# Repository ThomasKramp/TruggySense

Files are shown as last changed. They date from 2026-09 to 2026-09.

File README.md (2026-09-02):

# TruggySense

This repository contains two generations of the project:

| Folder | Description |
|---|---|
| [`TruggySense_v1`](./TruggySense_v1) | Original system, developed by **[Robbe Elsermans](https://github.com/RobbeElsermans)**. Companion paper: [arXiv:2505.07399](https://arxiv.org/abs/2505.07399) |
| [`TruggySense_v2`](./TruggySense_v2) | Hardware and firmware redesign for reproducibility, developed by **Thomas Kramp**, building on v1 |

Each subfolder has its own README with details on `cad/`, `code/`, and `docs/`.

---

## License

Unless stated otherwise, **original content created for this project** — documentation,
CAD/schematic designs, and project-authored source code — is licensed under
**[CC BY-SA 4.0 (Attribution-ShareAlike 4.0 International)](https://creativecommons.org/licenses/by-sa/4.0/)**.
The full legal text is in [`licence.txt`](./TruggySense_v1/licence.txt) (identical copy also in `TruggySense_v2/`).

In short, if you reuse or build on this work you must:
- **Attribute** the original creator(s) (Robbe Elsermans for v1, Thomas Kramp for v2) and link back to this repository,
- **Indicate any changes** you made,
- **Share any adapted/derivative version under the same license** (CC BY-SA 4.0 or a compatible license).

### What this license does *not* cover

CC BY-SA is intended for creative/documentation works, not for reused third-party software or hardware libraries. The following are **excluded** from the CC BY-SA grant above and remain under their own original licenses/terms:

- **Third-party code libraries** vendored under `code/**/lib/` (e.g. encoder libraries, `TimerInterrupt_Generic`, and similar dependencies pulled in via PlatformIO or copied manually). Check each library's own header/license file or upstream repository before reuse.
- **Vendor-exported component/footprint libraries** under `cad/KiCAD/**` (e.g. `Capture/`, `Quadcept/`, manufacturer `.zip` libraries). These originate from component manufacturers or distributors and are subject to their own terms.
- **Any datasheet, manual, or reference material** included for convenience (e.g. under `docs/`), which remains the property of its original publisher.
- **Trademarks and product names** referenced in this project — including *Team Corally Kagama*, *Teensy*, and other component/brand names — belong to their respective owners. Their use here is purely descriptive (identifying compatible hardware) and does **not** imply affiliation with, sponsorship by, or endorsement from those companies.

If you plan to redistribute or build a product on top of this repository, you are responsible for independently verifying the license terms of any third-party component you rely on.

### Hardware & safety disclaimer

This project involves custom electronics (battery connections, power protection, motor control) built for an RC vehicle platform. It is shared **as-is, for research and educational purposes**:

- No warranty is made regarding the safety, reliability, or fitness of any design for a particular purpose — see the full disclaimer in Section 5 of [`licence.txt`](./TruggySense_v1/licence.txt).
- Building or operating hardware based on this repository (batteries, power electronics, motorized vehicles) carries inherent risk. Do so at your own risk and with appropriate care.
- The authors and Cosys-Lab / University of Antwerp accept no liability for damages, injury, or losses arising from use of this material.

### Note on university/thesis materials

This repository is the output of Master's thesis work supervised by Cosys-Lab. Any university-internal documents (guidelines, templates) are included for context only and remain the property of the University of Antwerp; they are not licensed for reuse under the terms above.

---

## Questions about reuse or licensing

Open an issue on this repository, or reach out via Cosys-Lab, University of Antwerp.

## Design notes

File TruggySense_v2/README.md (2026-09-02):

# TruggySense: Hardware and Firmware Redesign for Reproducibility

The continuation of the [TruggySense](https://github.com/Cosys-Lab/TruggySense), that was  originally developed by Robbe Elsermans, a new off-road era of (autonomous) RC-vehicle.

Further developed by Kramp Thomas through Cosys-Lab at University of Antwerp.

Welcome to the readme! A list of what this repo includes

- all files related to the end product,
- source code,
- manuals of the final system.

## cad
Everything related to specialized mounts, holders, and cases to build upon the Team Corally Kagama 1/8 RC vehicle chassis. 
Furthermore, it contains also schematics and circuits drawn in KiCAD.

## code

## docs

## Future perspectives

## licence
BY-SA 4.0 (Attribution-ShareAlike 4.0 International)
See [licence.txt](licence.txt) for the disclaimer

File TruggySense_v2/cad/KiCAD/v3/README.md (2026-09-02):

## KiCAD

- **1_logic_board**:        The board-design and electrical schematic that contains the LLC, most sensors and connector points.
- **2_power_board**:        The board-design and electrical schematic that contains the connection to the battery and provides power to the motors.
- **sensor_position**:      The board-design and electrical schematic of the GNSS/GPS module.
- **sensor_temperature**:   The board-design and electrical schematic of the temperature sensor.

- **io_protection_buffer**: An electrical schematic of the protection buffer, for certain input purposes, used in the logic board.
- **io_protection_input**:  An electrical schematic for the input protection, used in the logic board.
- **io_protection_output**: An electrical schematic for the output protection, used in the logic board.

- **layout_nrf24l01**:      A generic board-layout for nRF24L01 modules, used in the logic board.
- **layout_pim448**:        A generic board-layout for motion sensor, used in the logic board.

- **recreation_ina219**:    A recreation of both the electrical schematic and board-design, for the low-current sensor.
- **recreation_lm2596**:    A recreation of both the electrical schematic and board-design, for the voltage converter (5V --> 3V3).

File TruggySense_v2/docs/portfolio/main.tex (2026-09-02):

\documentclass[ti,oneside,10pt]{uantwerpenreport}
% Run in terminal:  export TEXINPUTS=.:./classes//

\usepackage[english]{babel} % load the proper language(s)

% ---------------------- Document variables ----------------------
\title{TruggySense: Hardware and Firmware Redesign for Reproducibility}
\subtitle{Master's Thesis Portfolio}
\author{Thomas Kramp}
\affiliation{University of Antwerp | Department Electronics, Information and Communication Technology}
\address{Groenenborgerlaan 171, 2020 Antwerpen, Belgium\\
    M:\@ thomas.kramp@student.uantwerpen.be
}
\extra{Portfolio}
\versionyear{2026}

\titlepageimage{images/design/assembly/v2/full_assembly.png}
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
                \midrule
                    \csvreader[
                        head to column names,
                        late after line=\\,
                    ]{./databases/modules#2/stock.csv}{}{
                        \raggedright\Component &
                        \StockAndPrice{\DigiKeyStock}{\DigiKeyPrice}{\DigiKeyURL} &
                        \StockAndPrice{\FarnellStock}{\FarnellPrice}{\FarnellURL} &
                        \StockAndPrice{\MouserStock}{\MouserPrice}{\MouserURL} &
                        % Optional columns
                        \UseOptionalSupplier{#4} &
                        \UseOptionalSupplier{#5}
                    }
                \bottomrule
            \end{tabular}
        \end{adjustbox}
        \label{tab:#1_available_stock}
    \end{table}
    \vspace{-9pt}
    \noindent\textit{This stock was checked on #3.}
    \par\smallskip
}

% Old-New image comparison
\usepackage{pgffor} % for loops

\newcommand{\DualColumnWidth}{0.47}

\newsavebox{\ImgA}
\newsavebox{\ImgB}
\newlength{\ImgHA}
\newlength{\ImgHB}

\newcommand{\ImageComparison}[3]{
    % #1 = main caption
    % #2 = main label
    % #3 = list: {imgA/capA/imgB/capB, ...}

    \begin{figure}[h!]
        \centering
        \caption{#1}
        \label{fig:#2}

        \foreach {\imgA}/{\capA}/{\imgB}/{\capB} in {#3} {

            % Measure images at fixed width
            \sbox{\ImgA}{}
            \sbox{\ImgB}{}
            \setlength{\ImgHA}{\ht\ImgA}
            \setlength{\ImgHB}{\ht\ImgB}

            \begin{subfigure}{\DualColumnWidth\textwidth}
                \centering
                \ifdim\ImgHA>\ImgHB
                    % Image A is taller → scale it down
                    
                \else
                    % Image A is smaller → keep width
                    
                \fi
                \caption{\capA}
            \end{subfigure}
            \begin{subfigure}{\DualColumnWidth\textwidth}
                \centering
                \ifdim\ImgHB>\ImgHA
                    % Image B is taller → scale it down
                    
                \else
                    % Image B is smaller → keep width
                    
                \fi
                \caption{\capB}
            \end{subfigure}

            \par\vspace{0.5em} % new row spacing
        }
    \end{figure}
}
\newcommand{\ComponentTable}[1]{
    The components used are:
    \Needspace{10\baselineskip}
    \begin{table}[h!]
        \centering
        \begin{adjustbox}{max width=\textwidth}
            \begin{tabular}{L{2.5cm} c c l}
                \toprule
                    \textbf{Component} & \textbf{Tag} & \textbf{Name} & \textbf{Function} \\
                \midrule
                    \csvreader[
                        head to column names,
                        late after line=\\,
                    ]{./databases/design/#1}{}{
                        \Component & \Tag & \Name & \Function
                    }
                \bottomrule
            \end{tabular}
        \end{adjustbox}
    \end{table}
}
\newcommand{\BomLink}[2]{
    \IfStrEq{#2}{-}{#1}{                    % If
        \href{#2}{\textbf{#1}}   % Else
    }
}

% Setup checks
\usepackage{pifont}
\newcommand{\cmark}{\ding{51}} % ✔
\newcommand{\xmark}{\ding{55}} % ✘

% I²C highlight command
\usepackage{soul}
\newcommand{\IICUses}[1]{\textcolor{teal}{#1}}
\newcommand{\IICForb}[1]{\textcolor{purple}{\st{#1}}}

\sisetup{
    detect-all,
    group-separator = {,},
    group-minimum-digits = 4
}
\makeatletter
% \csvset{
%     before reading=\catcode`\%=12
% }
\makeatother

\begin{document}
\maketitle

\frontmatter
\tableofcontents

\mainmatter
% To Do list:
% - Complete AI usage document.

\chapter{Introduction}
% ---------------------- Introduction ----------------------
Last year, as of 2026, the development towards a off-road Remote Controlled Vehicle, called the TruggySense, started.
The system included sensors that could measure speed, acceleration, orientation, power consumption, temperature and location in real-time.
This was needed, since it was the groundwork, towards creating an Advanced Data Acquisition System (ADAS).
Eventually the goal is to add technologies that are present in most of todays smart cars, such as: anti-lock braking system (ABS), lane keeping, and traction control.

The thesis had proven to be able to gather real-time data, resulting in an astounding success, though it had a glaring flaw that led to two problems.
The assembly of the TruggySense Version 1 (TSV1) was complex and fault-prone (as shown in Fig.~\ref{fig:truggysense_version_1}).
This would mean that duplicating or modifying the system, would need rigorous debugging and be notably time-consuming.

\begin{figure}[h!]
    \centering
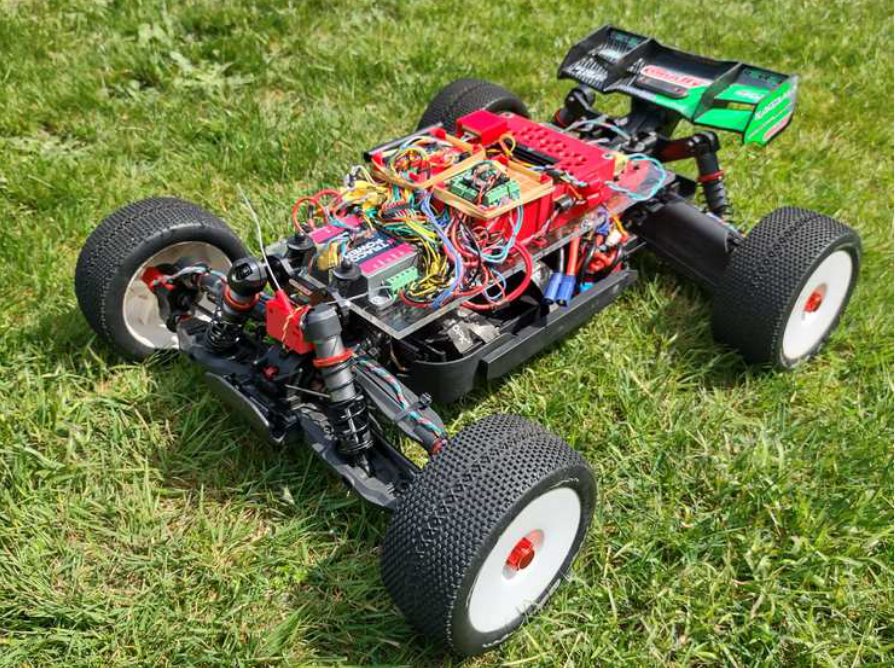
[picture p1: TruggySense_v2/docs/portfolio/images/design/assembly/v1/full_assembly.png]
	
	\caption{
		TruggySense version 1.
	}
	\label{fig:truggysense_version_1}
\end{figure}

To solve this, most of the components shall be integrated on a custom-made Printed Circuit Board (PCB).
Besides this other expansions this project will aim to include are:
\begin{itemize}
    \item Support for Individual Wheel Drive (IDW).
    \item Expansion possibility to add redundancy.
    \item Integration of ROS2 (Robot Operating System 2).
\end{itemize}

\subsection{Available middleware}
Note that a previous attempt was made to integrate ROS2 on the TruggySense.
Alternatives for this include ArduPilot, PX4, ZeroMQ, and LCM (Lightweight Communications and Marshalling).
Each of them having their advantages and disadvantages:
\begin{itemize}
    \item ArduPilot and PX4 are competitors of each other, both boasting an open-source autopilot firmware.
          These projects were specifically designed for aerial vehicles, later adding support for land vehicles.
          With both ArduPilot and PX4 being designed for autonomy, which isn't suitable for Remote Controlled Vehicles (RCV);
          and having a high reliance on GPS data, which isn't always available in off-road situations.
    \item ROS2 as an open-source middleware framework, working with a Pub-Sub system.
          This project is known to have high latency or bandwidth budgeting, creating the need to alter the software for real-time applications.
    \item ZeroMQ and LCM are open-source messaging libraries, with LCM focussing on real-time data acquisition.
          These projects are both ethernet dependent, ZeroMQ working with TCP and LCM working with UDP.
          With ZeroMQ having no built-in reliability, needing to built your own reconnection and packet loss handling;
          and LCM acting more as a logger than a communication step between the controllers.
\end{itemize}

For this thesis we will continue on the assumption that ROS2 will be implemented, despite its latency issues.

\subsection{Conclusion}
Most of the ground work has been done, yet a small part of the documentation provided is either conflicting, false or non-existing.
Thus this will be an iterative project, first creating a prototype and based on the results and inevitable mishaps a full-fletched PCB will be created.
The goal of this project will be to create second iteration of the TruggySense (TSV2), that will provide a similar performance to the TSV1, but is easier to assemble.

\chapter{Modules and Sensors}       % ---------------------- Modules and Sensors ----------------------
\section{Framework layout} 
The TruggySense makes use of two controllers: A High Level Controller (HLC) and Low Level Controller (LLC).

The LLC will act as a Data Acquisition System (DAQ), control the base components of the RCV and communicate with other components.
The modules used for these purposes are:
\begin{table}[h!]
    \centering
    \begin{tabular}{p{0.3\textwidth}p{0.3\textwidth}p{0.3\textwidth}}
        Sensing: & Actuating: & Communicating: \\
        \begin{itemize}
            \item A motion sensor
            \item A GNSS/GPS
            \item Temperature sensors
            \item Four wheel encoders
        \end{itemize} &
        \begin{itemize}
            \item One to four Electronic Speed Controllers (ESC)
            \item A servo
        \end{itemize} &
        \begin{itemize}
            \item RC control communication
            \item Wireless data logging
        \end{itemize} \\
    \end{tabular}
\end{table}

\begin{figure}[h!]
    \centering
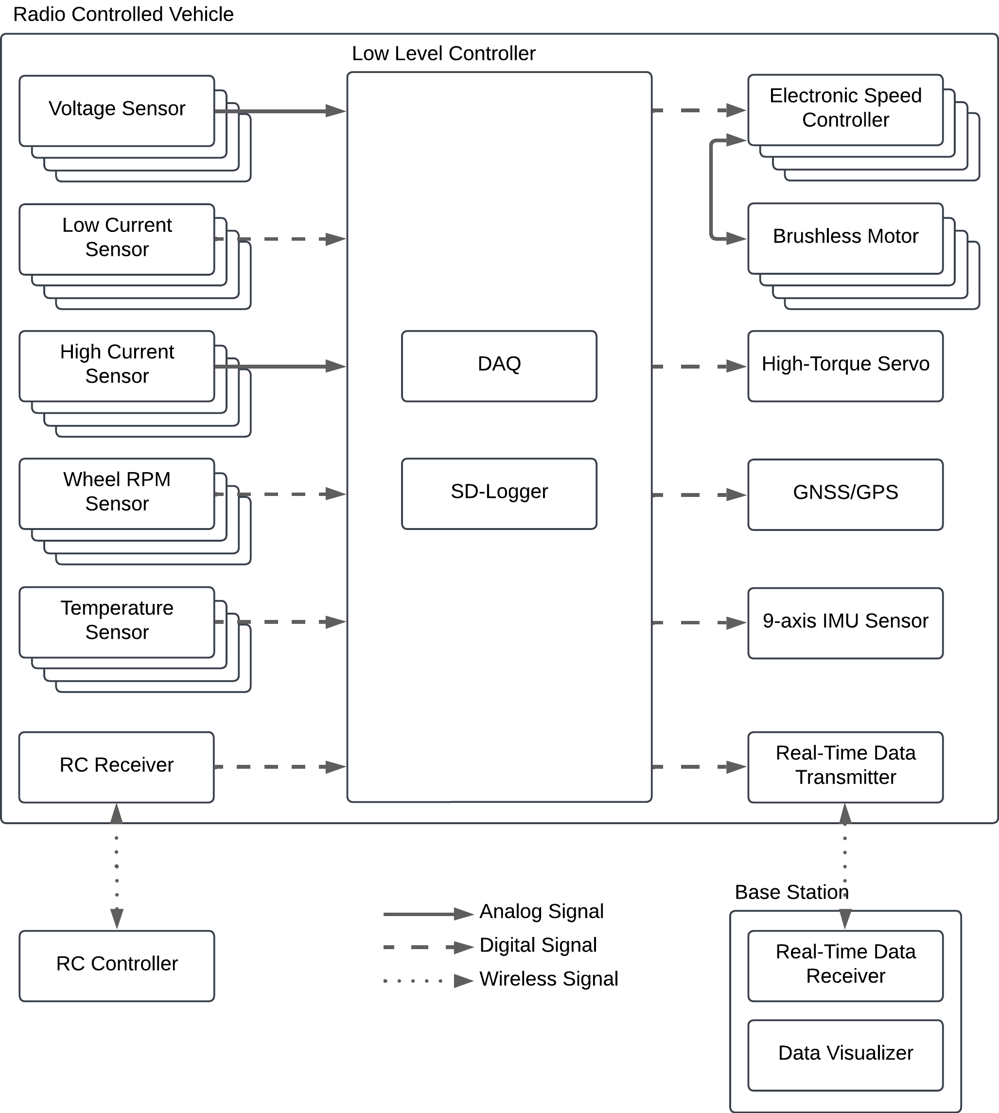
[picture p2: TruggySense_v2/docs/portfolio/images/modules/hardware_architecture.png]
	
	\caption{
		Hardware architecture of the LLC.
	}
	\label{fig:hardware_architecture}
\end{figure}

The HLC on the other hand will be further expanded on in subsequent stages of this multiple thesis project, 
but it is meant to take the data from the LLC and return instructions to make it a autonomous vehicle.

\section{Low level controller}      % Controllers
\label{sec:LLC}
The module that was both documented and used in the TSV1, was the Teensy 4.1.

As previously discussed ROS2 is intended to be implemented.
This will be done on the HLC, but this is to0 robust for the LLC, thus \href{https://micro.ros.org/docs/overview/hardware/}{Micro-ROS} will be implemented.
This means that we only need to consider Micro-Ros compatible boards fot the LLC.
\HardwareTable
    {low_level_controller}
    {controller/low-level/data.csv}
    {L{4cm} c c r l r}{
        \textbf{Board} & \textbf{RAM} & \textbf{Flash} & 
        \multicolumn{2}{l}{\textbf{Available Pins}} & \textbf{Programmer} \\
    }{
        \href{\BoardURL}{\Component} &
        \RAM & \Flash & \PinHeaderColor{\PinHeaders} &
        \ExtraPins & \ProgrammerColor{\Programmer}
    }

\subsection{Restrictions}
This is an open-source project that any hobbyist should be able to assemble.
For these purposes the following should hold:
\RmLstWS
\begin{itemize}
    \item The LLC needs to be easy to attach and detach from the PCB, meaning that the dev-boards shall be used (unless the chip can easily be soldered on such as with the ESP32).
    \item Programming the software should be simple and available to every user. As such only boards supported by te ArduinoIDE will be used.
    \item The boards should be available on \href{https://www.digikey.be/en}{DigiKey}, \href{https://be.farnell.com/}{Farnell} or \href{https://www.mouser.be/}{Mouser} (and their price should be considered).
    \item The previous model of the TruggySense used the Teensy 4.1 as a LLC. This model contained all needed pins/peripherals to support the connected sensors and actuators, though it did not leave any for future expansions. Thus the LLC should have at least equal or more pins/peripherals available.
\end{itemize}
With these conditions the following boards will not be used:
\RmLstWS
\begin{multicols}{3}
    \begin{itemize}
        \item Renesas EK RA6M5
        \item Espressif ESP32
        \item Arduino Portenta H7
        \item Raspberry Pi Pico RP2040
        \item ROBOTIS OpenCR 1.0
        \item Teensy 3.2
        \item STM32L4 Discovery IoT
        \item Olimex LTD STM32-E407
        \item Arduino Zero
        \item ST NUCLEO-F446ZE
        \item ST NUCLEO-F746ZG
        \item ST NUCLEO-H743ZI
    \end{itemize}
\end{multicols}
\RmLstWS
\RmTabWS
\StockTable
    {low_level_controller}
    {/controller/low-level}
    {28/01/2026}
    {Kiwi}
    {Conrad}
\subsection{Conclusion}
This shows that the only viable option is the Teensy 4.1.
\RmTabWS
\begin{table}[h!]
    \centering
    \caption{Peripherals of Teensy 4.1 dev-board}
    \begin{adjustbox}{max width=\textwidth}
        \begin{tabular}{l c c c c c c c c c c}
            \toprule
                \textbf{Board} & \textbf{GPIO} & \textbf{ADC} &
                \textbf{Timers} & \textbf{PWM} & \textbf{UART} &
                \textbf{SPI} & \textbf{I2C} & \textbf{CAN} & \textbf{SDIO} \\
            \midrule
                \small{Teensy 4.1} & 42 & 
                \small{18$\times$12-bits pins} & \small{4$\times$32-bits} & 
                \small{35 pins} & 8 & 3 & 3 & 2 & 1 \\
            \bottomrule
        \end{tabular}
    \end{adjustbox}
    \label{tab:teensy_peripherals}
\end{table}
\subsection{Power management}
It is recommended to power Teensy 4.1 with a 5V power source, which its on board DC-to-DC converter will convert to 3V3.
A 3V3 could be connected to the 3V3 pin, but is not discouraged.
Its power consumption is estimated to be 100mA (not clear if this is for a 3V3 supply or a 5V supply).
And the maximum allowed power draw for peripherals, that draw power from it, is 250mA at 3V3.

We will assume for now that: the 100 the teensy draws 100mA after the 5V-to-3V3 conversion, and that the peripherals use 200mA of the allowed current.

\hspace{12pt} $P = 3.3V * I_{3V3} = 3.3V * (100mA + 200mA) \approx 1W$

\hspace{12pt} $ I_{5V} = \frac{P}{5V} = \frac{1W}{5V} = 200mA$
\section{High level controller}
\label{sec:HLC}
The module stated in the TSV1 documentation and used was the Nvidia Jetson Nano.
This component cannot be changed as a requirement and thus falls out of this projects scope.
\RmTabWS
\StockTable
    {board_components}
    {/controller/high-level}
    {28/01/2026}
    {Conrad}
    {Antratek}
\subsection{Power management}
The Nvidia Jetson Nano requires a minimum power source of 2A at 5V, but can demand 4A under load.
\newpage

\section{Motion}                    % Sensors
\label{sec:IMU}
In the documentation of the TSV1, on page 10, the following was stated regarding the orientation:

\Quoting{
    The motion of the vehicle will be a vital aspect of the system, since it determines the stability of the vehicle. 
    Therefore, it needs a sensor that can sens movements in the X, Y and Z direction. 
    For this, typically, an Inertial Measurement Unit (IMU) of some degree of freedom is used.
    In our setup, we'll use a 9-Degree-of-Freedom (9DOF) IMU sensor; including angular velocity, acceleration and orientation based on a compass or magnetic sensor.
}

The module that was both documented and used by the TSV1, was the \href{https://www.adafruit.com/product/4754}{BNO085}.
\HardwareTable
    {motion_sensor}
    {sensor/motion/data.csv}
    {L{2cm} L{2.5cm} L{1.5cm} r c l c}{
        \textbf{Sensor} &
        \textbf{Protocol} &
        \textbf{Package} &
        \multicolumn{3}{c}{\textbf{Supply range (V)}} &
        \textbf{Accuracy (DoF)} \\
    }{
        \Component &
        \ProtocolColor{\Protocol} &
        \PackageColor{\Package} &
        \MinSupply & - & \MaxSupply &
        \Accuracy
    }
\RmTabWS
\RmTabWS
\StockTable
    {motion_sensor}
    {/sensor/motion}
    {28/01/2026}
    {Kiwi}
    {Conrad}
\subsection{Conclusion}
Of the two viable options, that being the BNO085 and ICM-20948, the latter is the better choice.
This is due to its lower cost, being more available, smaller board footprint and not conflicting with any other I²C addresses of other modules (see Table~\ref{tab:i2c_address_table}), while still having the same amount of DoF.
\subsection{Power management}
The ICM-20948 requires a average power source of $\sim$5mA at 3V3.
\section{Position}
\label{sec:GPS}
In the documentation of the TSV1, on page 9, the following was stated regarding the positioning:

\Quoting{
    Absolute positioning can be used to estimate the speed of the vehicle. 
    This estimation can be combined with wheel encoders to give a more precise estimation of the actual vehicles speed.
}

The module that was selected in the TSV1, was the \href{https://nl.aliexpress.com/item/1005005211498523.html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}{QUESCAN G10A-F30}.
The module that was implemented was the M10FD.
\HardwareTable
    {position_sensor}
    {sensor/position/data.csv}
    {L{2.5cm} L{3.5cm} L{3cm} r c l c}{
        \textbf{Sensor} &
        \textbf{Protocol} &
        \textbf{Package} &
        \multicolumn{3}{c}{\textbf{Supply range (V)}} &
        \textbf{Accuracy (m CEP)} \\
    }{
        \Component &
        \ProtocolColor{\Protocol} &
        \PackageColor{\Package} &
        \MinSupply & - & \MaxSupply &
        \Accuracy
    }
\subsection{Restrictions}
Due to the wide range of modules, filtering will be required, thus the following should hold:
\RmTabWS
\begin{itemize}
    \item Higher accuracy is preferred, thus any module that has a \textgreater2m accuracy will not be considered unless the other options aren't viable.
    \item A smaller footprint is preferred.
    \item Protocols that can be chained together on a single bus, such as I²C and one-wire are preferred.
\end{itemize}
With these conditions the following boards will not be used:
\RmLstWS
\begin{multicols}{3}
    \begin{itemize}
        \item M10FD
        \item L86-M33
        \item PA1616D
        \item CAM-M8
        \item MAX-7
        \item MAX-M8
    \end{itemize}
\end{multicols}
\RmLstWS
\RmTabWS
\StockTable
    {position_sensor}
    {/sensor/position}
    {27/01/2026}
    {Kiwi}
    {Antratek}
\subsection{Conclusion}
Of the listed modules, the NEO-M9N-00B and TESEO-LIV3F are the only viable options.
Of the two viable options, that being the NEO-M9N-00B and TESEO-LIV3F, the latter is the better choice.
This is due to its lower cost, being more available, smaller board footprint and not conflicting with any other I²C addresses of other modules (see Table 2.26), while still having the smallest CEP.
\subsection{Power management}
The TESEO-LIV3F requires a average power source of $\sim$23mA at 3V3.
\section{Temperature}
\label{sec:TMP}
In the documentation of the TSV1, on page 4, the following was stated regarding the temperature sensor:

\Quoting{
    The primary objective of temperature measurements is to monitor the operational condition of all modules in terms of temperature. 
    When measuring temperature, it is possible to identify components nearing failure as well as equipment that may become too hot due to environmental factors or software-induced overheating.\\
    \hfill \break
    Temperature data can be collected at 100Hz. 
    However, in this system, such rapid measurements are unnecessary since we only monitor temperatures outside individual components. 
    Temperature readings must pass through the equipment before any significant increase is detected.
}

The module that was both documented and used by the TSV1, was the \href{https://www.digikey.be/nl/products/detail/analog-devices-inc-maxim-integrated/DS18B20/956983}{DS18B20+}.
Five of these sensors were daisy chained to each other and communicated using the one-wire protocol, with each of them being place against one of the following components:
Brushless motor, Electronic speed controller, Battery pack, Digital servo and High-level controller.
Though it was stated that the sensor for the digital servo was used for the Low-level-controller.
\HardwareTable
    {temperature_sensor}
    {sensor/temperature/data.csv}
    {L{3.5cm} L{3cm} L{1.5cm} r c l r c l c}{
        \textbf{Sensor} &
        \textbf{Protocol} &
        \textbf{Package} &
        \multicolumn{3}{c}{\textbf{Supply range (V)}} &
        \multicolumn{3}{c}{\textbf{Range (°C)}} &
        \textbf{Accuracy (°C)} \\
    }{
        \Component &
        \ProtocolColor{\Protocol} &
        \PackageColor{\Package} &
        \MinSupply & - & \MaxSupply &
        \TempMinTemperatureColor{\MinRange} & - & \MaxRange &
        +/- \Accuracy
    }
\subsection{Restrictions}
A digital sensor was used since sensors will be placed near high current carrier wires that run PWM pulses or the brushless motor, that operate on electromechanical principles.
This could cause significant disturbances to an analogue signal, making it less desirable - though it also could lead to packet loss in case of the digital sensors.

Besides this the pin count on the LLC is limited, making sensors that can be chained to the same bus more favorable.
For this purpose a separate PCB will be designed to make the chaining easier.
This means that the chosen component should be easily soldered using only a solder station.

Thus the following should be held in consideration when choosing a module:
\RmTabWS
\begin{itemize}
    \item Digital protocols are preferred.
    \item Protocols that can be chained together on a single bus, such as I²C and one-wire are preferred.
    \item The temperature sensors need to be mounted on the objects, thus modules that are encased cannot be used.
    \item The chip package should allow manual soldering.
\end{itemize}

With these conditions the following modules will not be used:
\RmTabWS
\begin{multicols}{3}
    \begin{itemize}
        \item DHT11
        \item DHT22
        \item LM35DZ/LM335/LM34
        \item BMP180
        \item TMP36
        \item BME280
    \end{itemize}
\end{multicols}
\RmLstWS
\RmTabWS
\StockTable
    {temperature_sensor}
    {/sensor/temperature}
    {19/01/2026}
    {Kiwi}
    {Otronic}
\subsection{Conclusion}
The LM75 will be chosen due to its low cost and its use of the I²C protocol, without coming into conflict with the addresses of other I²C modules (see Table~\ref{tab:i2c_address_table}).
\subsection{Power management}
There are five LM75 that each require a average power source of 1mA at 3V3 or 5V.
\section{Wheel speed}
\label{sec:ENC}
In the documentation of the TSV1, on page 6, the following was stated regarding the Wheel rotation sensor:

\Quoting{
    The speed of the wheels can be deducted through various approaches such as using a mirror and infra red light (bounce principle), use a white dot (or black) to give contrast and then use a color sensor, a light optic encoder disc or a magnet with a hall effect sensor. 
    This list goes on as many approaches are possible.
    \hfill \break \break
    In this case, the selected approach must endure in harsh conditions where dirt and water can enter the room quite often. 
    The rigidity of the wheel can also not be contaminated. Unbalanced wheels at high RPM’s can cause damage and instability.
    \hfill \break \break
    Therefore, some approaches must be eliminated such as the color sensor, infra-red and mirror - dirt can spoil the party - and optic encoders have an exception. 
    If we had the room to make sure the equipment was well maintained in a dust and water proof encasing, this could work.
    Unfortunate, the space is limited.
}

The module that was both documented and used by the TSV1, was the \href{https://www.mouser.be/ProductDetail/Diodes-Incorporated/AH3323A-P-B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}{AH3323A-P-B}.
Four of these Uni-Polar sensors were placed on the module, one on each wheel, due to magnetic flux being unaffected by water and dirt.
They provide either a '0' or a '1' if there is any magnetic flux detected, while not needing a reset, as the case with Bi-Polar sensors.

\HardwareTable
    {wheel_speed}
    {sensor/wheel/data.csv}
    {L{4.5cm} L{3cm} L{2.5cm} r c l c c c}{
        \textbf{Sensor} &
        \textbf{Protocol} &
        \textbf{Package} &
        \multicolumn{3}{c}{\textbf{Supply range (V)}} &
        \textbf{Input current (mA)} &
        \textbf{Output current (mA)} &
        \textbf{Accuracy (G)} \\
    }{
        \Component &
        \ProtocolColor{\Protocol} &
        \PackageColor{\Package} &
        \MinSupply & - & \MaxSupply &
        \MaxInA & \MaxOutA &
        \Accuracy
    }

\subsection{Restrictions}
Due to the limited space near the wheels, though hole packages are preferred (such a SIP-3).

Besides the package, the operating voltage should be 3V3, since the Teensy 4.1 isn't protected for 5V signals on its pins.
To convert any 5V signal, a circuit that can convert it to 3V3 would be required, which will only increase the cost and introduce more components that could possibly fail.

Thus the following should be held in consideration when choosing a module:
\RmLstWS
\begin{itemize}
    \item Though hole packages are preferred.
    \item Modules using a 3V3 supply are preferred 
\end{itemize}

With these conditions the following modules will not be used:
\RmLstWS
\begin{multicols}{2}
    \begin{itemize}
        \item TLE4905LE6433
        \item US5881LUA-AAA-000-BU
    \end{itemize}
\end{multicols}
\RmLstWS
\RmTabWS
\StockTable
    {wheel_sensor}
    {/sensor/wheel}
    {28/01/2026}
    {Kiwi}
    {Conrad}
\subsection{Conclusion}
The AH3323A-P-B is still the most accurate and more available than its counterpart.
Thus the AH3323A-P-B will be chosen.
\subsection{Power management}
There are four AH3323A-P-B that each require a average power source of 5mA at 3V3.

\section{Motor}                     % Actuators
\label{sec:MTR}
The module used in the TSV1 was the Corally Kuron 825.
This component cannot be changed as a requirement and thus falls out of this projects scope.

\noindent\textit{No stock of the Corally Kuron 825 was found on available distributors as of 27/01/2026.}

The Corally Kuron 825 requires a maximum power source of 185A between 11V1 and 22V2.
\section{Speed controller}
\label{sec:ESC}
The module used in the TSV1 was the Corally Torox 185.
This component cannot be changed as a requirement and thus falls out of this projects scope.

\noindent\textit{No stock of the Corally Torox 185 was found on available distributors as of 27/01/2026.}

The Corally Torox 185 requires a minimum power source of 100mA at 5V.
\section{Steering servo}
\label{sec:SRV}
The module used in the TSV1 was the DS3225 25KG servo.
This component cannot be changed as a requirement and thus falls out of this projects scope.

\noindent\textit{No stock of the DS3225 was found on available distributors as of 27/01/2026.}

The DS3225 25KG servo requires a minimum power source of 4mA at 5V in idle state, but while rotating it will have a peak current of 1.9A.

\section{RC Control}  % Communication
\label{sec:RCC}
The module stated in the TSV1 documentation and used was the FLySky \href{https://nl.aliexpress.com/item/1005006134316987.html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}{FS-X6B}, which communicates with a \href{https://nl.aliexpress.com/item/1005006860791905.html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}{FS-I6X} module inside a remote.
This component cannot be changed as a requirement and thus falls out of this projects scope.

\noindent\textit{No stock of the FS-X6B was found on DigiKey, Farnell, Mouser, Kiwi Electronics, Conrad, Antratek or Otronic as of 27/01/2026.}
\subsection{Conclusion}
Since this is an external modules that cannot be integrated on the PCB, it is outside this project's scope to change this module.
Thus we'll continue using the FS-I6X and FS-X6B.
\subsection{Power management}
The FS-X6B requires a power source of 50mA at 5V while transmitting or receiving.
\section{Wireless logging}
\label{sec:LRC}
In the documentation of the TSV1, on page 11-12, the following was stated regarding the long range controller:

\Quoting{
    The communication between vehicle and base station will have a maximum of 500 m, since the FS-X6B transceiver has a range of 500m and 1500m under ideal conditions.
    Thus looking at modules that support longer ranges would hurt nobody.
    \hfill \break \break
    A connection can be setup in two ways.
    Either via a P2P connection with our own modules that connects the RCV and base station, or an access point onto the RCV itself where the user can connect to. 
    With this access point on the vehicle itself, direct communication can be established with any device that supports WiFi.
    This makes connection easier to the vehicle.
}

The module that was both documented and used by the TSV1, was the \href{https://nl.aliexpress.com/item/32783191387.html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}{E01-ML01DP5}.
This is a nRF24LO1 module with integrated PA/LNA, making it difficult to find on large distributor marketplaces - such as DigiKey, Farnell and Mouser - since they are mostly non-certified modules.
Thus possible alternatives should be looked towards:
\RmLstWS
\begin{itemize}
    \item nRF24LO1 modules work on 2.4GHz, have added circuits (PA/LNA) and use protocols of smaller size to boost their range.
    This means we could look towards other chips that use the same frequency range, so we have support of the WiFi infrastructure.
    Chips like these include the other nRF24LO1 modules and modules from the nRF52 with an external PA/PLA or optimized antenna.
    \item Sub-1GHz modules have a longer range and better penetration than 2.4GHz modules.
    Chips like these include the nRF905, TI CC11 and TI CC13 modules.
\end{itemize}

Wi-Fi/Bluetooth modules, such as the ESP32 or ATWINC1500, cannot be used with the same modifications as the nRF52.
The 2.4GHz radio is too tightly coupled to the Wi-Fi/Bluetooth protocols, that making changes is impossible.
This lowers the range of the modules drastically to but a few hundred meters at best.

Modules with a standard sub-1GHz protocol, such as LoRa, have the range, but might not have the needed infrastructure to support it (LoRa needs gateways) and have a limit on how many messages can be send per hour/day.
\begin{table}[h!]
    \centering
    \caption{Long range alternatives table}
    \begin{adjustbox}{max width=\textwidth}
        \begin{tabular}{l c c c c}
            \toprule
                \textbf{Module} & \textbf{Frequency} & \textbf{PA/LNA} & \textbf{Protocol} & \textbf{Estimated range} \\
            \midrule
                FLySky X6B  & 2.4 GHz & Moderate   & AFHDS 2A & $\sim$200-500m \\
                E01-ML01DP5 & 2.4 GHz & Integrated & ESB      & $\sim$800m-1.5 km \\
            \midrule
                CC11     & 433/868/915 MHz & Integrated & Software defined & \CommunicationRangeColor{$\sim$1-2km} \\
                CC13     & 433/868/915 MHz & Integrated & Software defined & \CommunicationRangeColor{$\sim$1-2km} \\
                CC25     & 2.4 GHz         & None       & Software defined & \CommunicationRangeColor{$\sim$50-100m} \\
                CC25     & 2.4 GHz         & External   & Software defined & \CommunicationRangeColor{$\sim$500-800m} \\
                ESP32    & 2.4 GHz         & None       & BLE/Wi-Fi        & \CommunicationRangeColor{$\sim$50-200m} \\
                nRF24    & 2.4 GHz         & None       & ESB              & \CommunicationRangeColor{$\sim$50-100m} \\
                nRF24L01 & 2.4 GHz         & Integrated & ESB              & \CommunicationRangeColor{$\sim$500m-1km} \\
                nRF52    & 2.4 GHz         & None       & BLE/Zigbee       & \CommunicationRangeColor{$\sim$50-100m} \\
                nRF52    & 2.4 GHz         & External   & BLE/Wi-Fi        & \CommunicationRangeColor{$\sim$500m-1km} \\
                nRF905   & 433/868/915 MHz & Moderate   & Hardware defined & \CommunicationRangeColor{$\sim$500m-1km} \\
            \bottomrule
        \end{tabular}
    \end{adjustbox}
    \label{tab:long_range_alternatives}
\end{table}
\RmTabWS
\RmTabWS
\HardwareTable
    {long_range_communication}
    {communication/nrf/data.csv}
    {L{3cm} L{3.5cm} L{3cm} r c l c c c}{
        \textbf{Sensor} & \textbf{Protocol} & \textbf{Package} & 
        \multicolumn{3}{c}{\textbf{Supply range (V)}} &
        \textbf{Frequency} & \textbf{Antenna} & \textbf{Range}\\
    }{
        \Component & \ProtocolColor{\Protocol} & 
        \PackageColor{\Package} &
        \MinSupply & - & \MaxSupply &
        \Frequency & \Antenna & \CommunicationRangeColor{\Range}
    }

\subsection{Restrictions}
For the module to be useful it first needs to have a longer range than the RC communication module (500m), and should even exceed this.
\StockTable
    {long_range_communication}
    {/communication/nrf}
    {01/02/2026}
    {Conrad}
    {Otronic}
\subsection{Conclusion}
The two viable options are the BDE-RFM208P and WIRL-WMB8 Metis-e.
Upon further research the \href{https://www.bdecomm.com/uploads/2021913/20210913173678807880.pdf}{BDE-RFM208P} needs a \href{https://www.ti.com/tool/LAUNCHXL-CC1352P#order-start-development}{TI CC1352P development kid} which would cost 50\$.
This isn't a software that is free to use software and thus falls out of the constraints of this project.
As for the \href{https://www.we-online.com/en/components/products/METIS-E}{WIRL-WMB8 Metis-e} can only be programmed using a software that is only available for Windows, and thus falls out of the constraints of this project.
\newpage
Since both the viable options are not available, we will return to the NRF24L01.
Note that these boards are only useful if a PA/PLA is present.
\RmFigWS
\begin{figure}[h!]
    \caption{Difference between PA/LNA and none ~\cite{Dejan2022}.}
    \centering
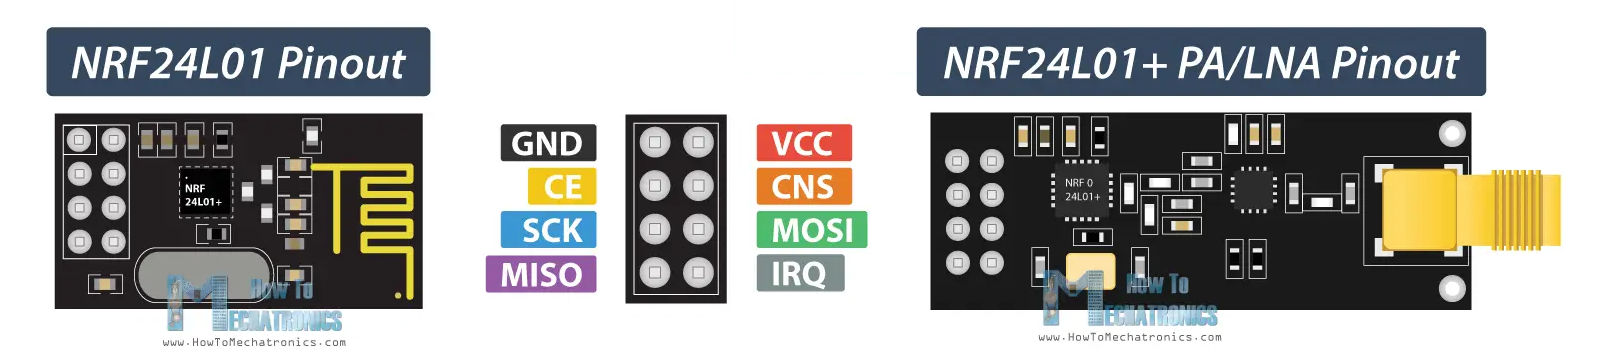
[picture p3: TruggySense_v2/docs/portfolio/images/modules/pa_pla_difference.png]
    
    \label{fig:pa_pla_difference}
\end{figure}
\RmFigWS
\subsection{Power management}
The NRF24L01 requires a power source of 13mA at 3V3 while transmitting or receiving.

\section{Supply}                    % Supply
The supply used in the TSV1 was the \href{https://www.amazon.com.be/Gens-ace-Batterie-connecteur-Connection/dp/B09YXRSTMT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}{Gens ace 4S Lipo Battery 5000mAh 14.8V 50C 4S Bashing RC Battery}.
When fully charged this module will provide a 16.8V supply that will diminish to 12.8V when discharging.
\RmTabWS
\begin{table}[h!]
    \centering
    \caption{Power draw estimation}
    \begin{adjustbox}{max width=\textwidth}
        \begin{tabular}{l r c c c c}
            \toprule
                \textbf{Module} & \textbf{Function} & \textbf{Quantity} & 
                \textbf{3V3 current (mA)} & \textbf{5V current (mA)} & 
                \textbf{5V load current (mA)} \\
            \midrule
                Teensy 4.1          & \hyperref[sec:LLC]{LLC}           & 1 &    & 200  & 200  \\
                NVIDIA JETSON NANO  & \hyperref[sec:HLC]{HLC}           & 1 &    & 2000 & 4000 \\
                ICM-20948           & \hyperref[sec:IMU]{Motion}        & 1 & 5  &      & \\
                TESEO-LIV3F         & \hyperref[sec:GPS]{Position}      & 1 & 23 &      & \\
                LM75                & \hyperref[sec:TMP]{Temperature}   & 5 & 1  &      & \\
                AH3323A-P-B         & \hyperref[sec:ENC]{Wheel speed}   & 4 & 5  &      & \\
                Torox 185           & \hyperref[sec:ESC]{Wheel Speed}   & 1 &    & 100  & 100  \\
                DS3225              & \hyperref[sec:SRV]{Servo}         & 1 &    & 4    & 1900 \\
                FS-X6B              & \hyperref[sec:RCC]{RC control}    & 1 &    & 50   & 50   \\
                nRF24L01            & \hyperref[sec:LRC]{Long range}    & 1 & 13 &      & \\
                ACS758              & \hyperref[sec:AMP]{Current}       & 1 & 4  &      & \\
                INA219              & \hyperref[sec:AMP]{Current}       & 4 & 1  &      & \\
            \midrule
                Total               &               &   & 74 & 2154 & 6250 \\
            \bottomrule
        \end{tabular}
    \end{adjustbox}
    \label{tab:power_draw_estimation}
\end{table}
\section{DC/DC converter}
\label{sec:power_conversion}
The modules stated in the TSV1 documentation were the \href{https://nl.aliexpress.com/item/1005006376332910.html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}{Mini560PRO-3.3V} and \href{https://nl.aliexpress.com/item/1005006376332910.html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}{Mini560PRO-5V}.
The modules that were used were the LA3484A and the TMDC 20-2411.

The entire system connected to the LLC will have a current draw of around 2.5A.
To make sure this current can be provided, a module that can provide at least 1.5 times that amount (3.75A) will be used.
The TMDC 20-2411 Isolated Module can provide a current of 4A, demands an 9-36V input - between which the battery's voltage swings remain - and can output a steady 5.1V.
This module might be replaced by its 40W (TMDC 40-2411) or 60W counterpart (TMDC 60-2411), depending on the current draw.

A benefit to this module is that the source and sink voltages are separated at both the positive and negative terminals.
That way the battery and motor can be connected to a PCB that is separated, both physically and with its ground plane, from the LLC PCB.
This will give the following benefits:
\RmLstWS
\begin{itemize}
    \item The logic board will be separated from the motor's return current, leading to less noise.
    \item Any drops in voltage or current spikes won't effect the 5V rail, leading to a stiffer supply.
\end{itemize}
\HardwareTable
    {DC/DC_converter}
    {power/converter/data.csv}
    {L{3cm} L{3cm} r c l r c l c}{
        \textbf{Sensor} & \textbf{Package} &
        \multicolumn{3}{c}{\textbf{Input voltage (V)}} &
        \multicolumn{3}{c}{\textbf{Output voltage (V)}} &
        \textbf{Max current (A)} \\
    }{
        \Component & \PackageColor{\Package} &
        \AboveValueColor{4.8}{\MinInV}  & - & \BelowValueColor{5}{\MaxInV} &
        \AboveValueColor{3.3}{\MinOutV} & - & \BelowValueColor{3.3}{\MaxOutV} &
        \BelowValueColor{0.2}{\MaxAmp}
    }
\subsection{Restrictions}
With these conditions the following boards will not be used:
\RmLstWS
\begin{multicols}{4}
    \begin{itemize}
        \item AMS1117-3.3
        \item AMS1117-5.0
        \item D45V5F5
        \item JW5068A
        \item LA3484A
        \item LM7805
        \item Mini560PRO-3.3V
        \item Mini560PRO-5V
        \item S13V20F5
        \item S7V8F5
        \item S9V11F5
        \item XL1509-5.0
        \item XL4015
        \item XL4016
    \end{itemize}
\end{multicols}
\RmLstWS
\RmTabWS
\StockTable
    {power_supply}
    {/power/converter}
    {02/02/2026}
    {Conrad}
    {Otronic}
\subsection{Conclusion}
There are four viable options: LM2596, MP2338GTL-Z, TPS62A0X, TPS631000DRLR.
Of these modules the LM2596 is the most expensive, both the board and its parts are readily available.
Besides that, all needed components of the board are easy to solder.
Thus the LM2596 will be used as an alternative to the integrated circuit provided on the LLC.
\section{Ampere meter}
\label{sec:AMP}
In the documentation of the TSV1, on page 8, the following was stated regarding the ampere meter sensor:

\Quoting{
    The current consumption of modules can give an indication on faulty hardware or even faulty software.
    It is more a monitoring value. Nevertheless, this ”monitoring” is vital in order to not overrun our hardware.
    \hfill \break \break
    For this, two methods of determining current consumption can be utilized:
    Shunt resistors, which measure the differential voltage across a resistor in series; 
    and Hall-effect sensors, which measure the current based on the magnetic field they create while passing through a conductor.
    \hfill \break \break
    We could divide high and low currents, where we measure the former with the hall effect sensing methodology and the latter with a shunt resistor.
}

The modules that wer both documented and used by the TSV1 were the \href{https://www.digikey.com/en/products/detail/allegro-microsystems/ACS758ECB-200B-PFF-T/2042748}{ACS758ECB-200B-PFF-T}, for high current, and \href{https://www.adafruit.com/product/1164}{INA169}, for low current.
\HardwareTable
    {high_ampere_meter}
    {sensor/current/data_high.csv}
    {L{1.5cm} L{4.5cm} L{3cm} r c l r c l r c l l}{
        \textbf{Sensor} &
        \textbf{Communication protocol} &
        \textbf{Package} &
        \multicolumn{3}{c}{\textbf{Supply range (V)}} &
        \multicolumn{3}{c}{\textbf{Readable voltage (V)}} &
        \multicolumn{3}{c}{\textbf{Readable current (A)}} &
        \textbf{Accuracy (mV/A)} \\
    }{
        \Component & \ProtocolColor{\Protocol} & 
        \PackageColor{\Package} &
        \MinSupply & - & \MaxSupply &
        \MinReadV & - & \MaxReadV &
        \MinReadA & - & \MaxReadA &
        \Accuracy   
    }
\RmTabWS
\RmTabWS
\HardwareTable
    {low_ampere_meter}
    {sensor/current/data_low.csv}
    {L{1.5cm} L{4.5cm} L{3cm} r c l r c l r c l}{
        \textbf{Sensor} &
        \textbf{Communication protocol} &
        \textbf{Package} &
        \multicolumn{3}{c}{\textbf{Supply range (V)}} &
        \multicolumn{3}{c}{\textbf{Readable voltage (V)}} &
        \multicolumn{3}{c}{\textbf{Readable current (A)}} \\
    }{
        \Component & \ProtocolColor{\Protocol} & 
        \PackageColor{\Package} &
        \MinSupply & - & \MaxSupply &
        \MinReadV & - & \MaxReadV &
        \MinReadA & - & \MaxReadA
    }

\subsection{Restrictions}
The motor has a power requirement of of 181A at a voltage between 11.1V and 22.2V, meaning the high current sensor needs to abide by this.

The remaining modules all work with either a 3V3 or 5V supply, but their current draw needs to be accounted for, since the INA-modules have a maximum current based on the Shunt-resistor.

With these conditions the following boards will not be used:
\RmLstWS
\begin{multicols}{2}
    \begin{itemize}
        \item ACS712
        \item ACS725
    \end{itemize}
\end{multicols}
\RmLstWS
\RmTabWS
\StockTable
    {amp_meter}
    {/sensor/current}
    {28/01/2026}
    {Kiwi}
    {Conrad}
\subsection{Conclusion}
For the high current application between the battery and the motor, the ACS758ECB-200U-PFF-T will be used as before.

For the low current applications between battery and computing board, the INA219 wil be used due to it supporting I²C without coming into conflict with the other I²C modules (see Table~\ref{tab:i2c_address_table}).
This will open three analogue ports up for later expansions.
Though slight modifications need to be made to these modules since their standard 100m\si{\ohm} (resulting in a maximum allowed current of 3.2A) will damage the INA-modules when the system is under load.

Instead of using four INA-modules, four will be implemented:
\RmLstWS
\begin{itemize}
    \item One for the overall current draw place at the input of the TMDC 20-2411.
    \item One for the HLC, which have a current draw between 2-4A.
    \item One for the RC-actuators, servo and motor control, which have a current draw between 100mA-2A.
    \item One for the LLC and its peripherals.
\end{itemize}

The INA219 can measure the voltage across a Shunt resistor, up to 320mV.
Thus the following rule should be followed:

\hspace{12pt} $I * R_{Shunt} < 320mV \Leftrightarrow R_{Shunt} < \frac{320mV}{I}$

\begin{table}[h!]
    \centering
    \caption{Current sensor modification}
    \begin{adjustbox}{max width=\textwidth}
        \begin{tabular}{l c rl rl rcl rcl}
            \toprule
                \textbf{Measuring} &
                \textbf{$I$} &
                \multicolumn{2}{c}{\textbf{$R_{Shunt}$}} &
                \multicolumn{2}{c}{\textbf{$V_{drop}$}} &
                \multicolumn{3}{c}{\textbf{Supply range (V)}} &
                \multicolumn{3}{c}{\textbf{Allowed supply (V)}} \\
            \midrule
                Overall logic current & 6.25A & $\frac{320mV}{6.25A} = 51.2m\Omega$ & $\Rightarrow R_{Shunt} = 50m\Omega$  & $ 6.25A * 50m\Omega $  & $= 312.5mV $ & 12.8 & - & 16.8 & 9    & - & 36 \\
                HLC                   & 4A    & $\frac{320mV}{4A} = 80m\Omega$      & $\Rightarrow R_{Shunt} = 50m\Omega$  & $ 4A * 50m\Omega $     & $= 200mV $   & 5.1  & - & 5.1  & 4.75 & - & 5.25 \\
                RC-actuators          & 2A    & $\frac{320mV}{2A} = 160m\Omega$     & $\Rightarrow R_{Shunt} = 100m\Omega$ & $ 2A * 100m\Omega $    & $= 200mV $   & 5.1  & - & 5.1  & 4.8  & - & 6.8 \\
                LLC + peripherals     & 200mA & $\frac{320mV}{200mA} = 1.6\Omega$   & $\Rightarrow R_{Shunt} = 100m\Omega$ & $ 200mA * 100m\Omega $ & $= 20mV $    & 5.1  & - & 5.1  & 4.8  & - & 5.5 \\
            \bottomrule
        \end{tabular}
    \end{adjustbox}
    \label{tab:current_sensor_modification_table}
\end{table}
This table shows that only two of the four INA-modules need their Shunt resistors replaced, and that by cutting their resistance in halve, they won't cause a voltage drop that will lead to the modules not functioning anymore.
\subsection{Power management}
There are four INA219 that each require a minimum power source of 1mA at 3V3, and one ACS758 that requires a minimum power source of 4mA at 3V3.
\section{Volt meter}
In the documentation of the TSV1, on page 7, the following was stated regarding the volt meter sensor:

\Quoting{
    Voltage monitoring is essential at several points in the system: 
    the total voltage of the battery pack, the individual cell voltages, and the voltages of the various power supplies.
    \hfill \break \break
    One approach is to measure these voltages directly using the Analogue to Digital Converter (ADC) on the Microcontroller Unit (MCU). 
    While this is a valid and straightforward method, analog signals are often susceptible to noise, which can distort the readings. 
    To mitigate this, additional hardware is needed to filter out unwanted noise.
    This can be achieved using analog components such as low-pass filters or inductive coils, or digitally using techniques like a moving average filter of size N.
    \hfill \break \break \newpage
    The chosen Teensy 4.1 MCU features 18 analog input pins, distributed across two ADC units. 
    For voltage measurements alone, a minimum of seven pins is needed: two for power sources, one for total battery voltage, and four for individual cell voltages. 
    While the ADC supports up to 12-bit resolution, it is generally recommended to use 10-bit resolution for stability and speed accordingly to the community. 
    This provides a usable range of \(2^{10}=1024\) levels, resulting in a voltage resolution of approximately \(\frac{3.3V}{1024bit}\simeq 3.22\frac{mV}{bit}\), assuming a reference voltage of 3.3V .
    Since many of the system voltages exceed 3.3V, voltage dividers must be used to scale the signals down to within the ADC’s readable range.
    After each voltage divider, a buffer stage (typically an op-amp configured as a voltage follower) should be added.
    This ensures the ADC sees a low-impedance source, while also preserving the integrity of the voltage divider's output.
}

The module that was selected in the TSV1, was the \href{https://www.adafruit.com/product/1083}{ADS1015}, but it also stated that it wouldn't use these and utilize the LLCs on-board ADCs.

\HardwareTable
    {volt_meter}
    {sensor/voltage/data.csv}
    {L{2cm} L{5cm} L{5cm} r c l r c l c}{
        \textbf{Sensor} &
        \textbf{Communication protocol} &
        \textbf{Package} &
        \multicolumn{3}{c}{\textbf{Supply range (V)}} &
        \multicolumn{3}{c}{\textbf{Output voltage (V)}} &
        \textbf{Accuracy} \\
    }{
        \Component &
        \ProtocolColor{\Protocol} &
        \PackageColor{\Package} &
        \MinSupply & - & \MaxSupply &
        \MinRange & - & \MaxRange &
        \Accuracy-bit
    }

\subsection{Restrictions}
Both of these sensors only have 4 I²C addresses, ranging from 0x48 to 0x4B.
Not only can they not support the 7 applications that need an ADC, but they also overlap with the other I²C modules (see Table~\ref{tab:i2c_address_table}).
\subsection{Conclusion}
Seven of the analogue pins of the LLC will be used in tandem with a buffer circuit that will convert any 5V signal to a safe 3V3.

\section{I²C address table overview}
\begin{table}[h!]
    \centering
    \caption{I²C address table}
    \begin{adjustbox}{max width=\textwidth}
        \begin{tabular}{l r c c c c c c c c c c c c c c c c c c c c}
            \toprule
                \textbf{Module} & \textbf{Function} & \textbf{\#} &
                \multicolumn{19}{c}{\textbf{Addresses}}\\
            \midrule
                BNO085      & Motion      & 0 &&&&&&&&&& 0x48 & 0x49 &&&&&&&&  \\
                ICM-20948   & Motion      & 1 &&&&&&&&&&&&&&&&&& 0x68 & \IICUses{0x69} \\
                NEO-M9N-00B & Position    & 0 &&&& 0x42 &&&&&&&&&&&&&&&  \\
                TESEO-LIV3F & Position    & 1 & \IICUses{0x3A} &&&&&&&&&&&&&&&&&  \\
                LM75        & Temperature & 5 &&&&&&&&&& 0x48 & 0x49 & 0x4A & \IICUses{0x4B} & \IICUses{0x4C} & \IICUses{0x4D} & \IICUses{0x4E} & \IICUses{0x4F} && \\
                INA219      & Current     & 4 && \IICUses{0x40} & \IICUses{0x41} & \IICForb{0x42} & \IICForb{0x43} & \IICUses{0x44} & \IICUses{0x45} & \IICForb{0x46} & \IICForb{0x47} & \IICForb{0x48} & \IICForb{0x49} & \IICForb{0x4A} & \IICForb{0x4B} & \IICForb{0x4C} & \IICForb{0x4D} & \IICForb{0x4E} & \IICForb{0x4F} && \\
            \bottomrule
        \end{tabular}
    \end{adjustbox}
    \label{tab:i2c_address_table}
\end{table}

Note that the INA219 can have 16 I²C addresses, but these depend on with which lines the A0 and A1 pins are connected (GND, VS, SDA or SCL).
Since the dev-board only allows for connection to GND and VS, the address range drops to 4 addresses.

\chapter{Module functionality}      % ---------------------- Module functionality ----------------------
\section{Protocols}
\subsection{ADC}
The LLC (Teensy 4.1) contains 14 ADC inputs.
These inputs are rated to allow voltages of up to 3.6V, but can only measure up to 3.3V.
To still be able to read the voltages of other rails, voltage deviders can be used.

\vspace{-18pt}
\begin{align}
    U_{out}                                   & = \frac{R_{2}}{R_{1} + R_{2}} \cdot U_{in} \\
    U_{out} \cdot (R_{1} + R_{2})             & = R_{2} \cdot U_{in} \\
    U_{out} \cdot R_{1} + U_{out} \cdot R_{2} & = R_{2} \cdot U_{in} \\
    U_{out} \cdot R_{1}                       & = R_{2} \cdot U_{in} - R_{2} \cdot U_{out} \\
    U_{out} \cdot R_{1}                       & = R_{2} \cdot (U_{in} - U_{out}) \\
    R_{2}                                     & = R_{1} \cdot \frac{U_{out}}{(U_{in} - U_{out})}
\end{align}
\vspace{-6pt}

With $R_{1}$ bridging between $U_{in}$ and $U_{out}$, and $R_{2}$ bridging between $U_{out}$ and GND.

It is best to use a 10kΩ - 100kΩ resitor value for $R_{1}$, to minimize the leak current, and to round the calculated value of $R_{2}$ to its closest E12 counterpart.

The LLC (Teensy 4.1) make use of 12-bit counters, resulting in $2^{n} = 2^{12} = 4096$ measurable voltage levels.
For this project this is set to 10-bit counters, resulting in 1024 measurable voltage level, meaning that the rounding error of the ADC can be found as follows:

\vspace{-18pt}
\begin{align}
    U_{per level} & = \frac{U_{cc}}{N} \\
                  & = \frac{3.3V}{1024} \\
                  & = 3.22mV
\end{align}
\vspace{-6pt}

\RmFigWS
\begin{figure}[h!]
    \centering
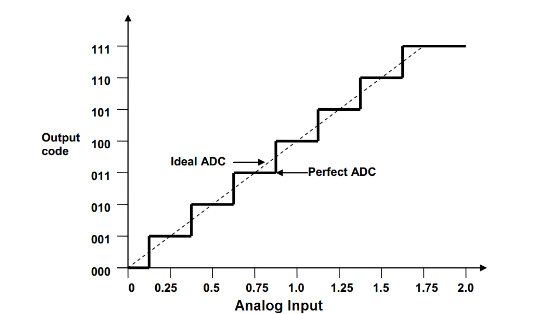
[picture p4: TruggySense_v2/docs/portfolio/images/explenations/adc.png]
    
    \caption{ADC voltage level conversion~\cite{Pefhany2017}.}
\end{figure}
\RmFigWS

This means that if we want to measure the 5V rail (ussually this is at 5.1V) dropping to 4.85V, that we would need a voltage devider of:

\vspace{-18pt}
\begin{align}
    R_{2} & = 10k\Omega \cdot \frac{3.3V}{(5.1V - 3.3V)} \\
          & = 18.33k\Omega \\
          & \approx 18k\Omega
\end{align}
\vspace{-6pt}

Our measured value at 4.85V then becomes:

\vspace{-18pt}
\begin{align}
    U_{out} & = \frac{18k\Omega}{10k\Omega + 18k\Omega} \cdot 4.85V \\
            & = 3.11786V \\
    U_{ADC} & = 3.11786V - (3.11786V \% 3.22mV) \\
            & = 3.11786V - 0.9mV\\
            & = 3.11696V
\end{align}
\vspace{-6pt}

If our software reverses the down-conversion with the measure data, we get a 0.0024V difference:

\vspace{-18pt}
\begin{align}
    U_{in} & = \frac{R_{1} + R_{2}}{R_{2}} \cdot U_{out} \\
           & = \frac{10k\Omega + 18k\Omega}{18k\Omega} \cdot 3.11696V \\
           & = 4.8486V
\end{align}
\vspace{-6pt}
\subsection{PWM}
The LLC (Teensy 4.1) contains 28 PWM outputs.
These outputs can generate a PWM at 3.3V.

The two most important aspects of a PWM signal are: its period (the dureation of the complete pulse, and the inverse of the frequency), and duty-cycle (a percentile of the period, in which the pulse is active).

\RmFigWS
\begin{figure}[h!]
    \centering
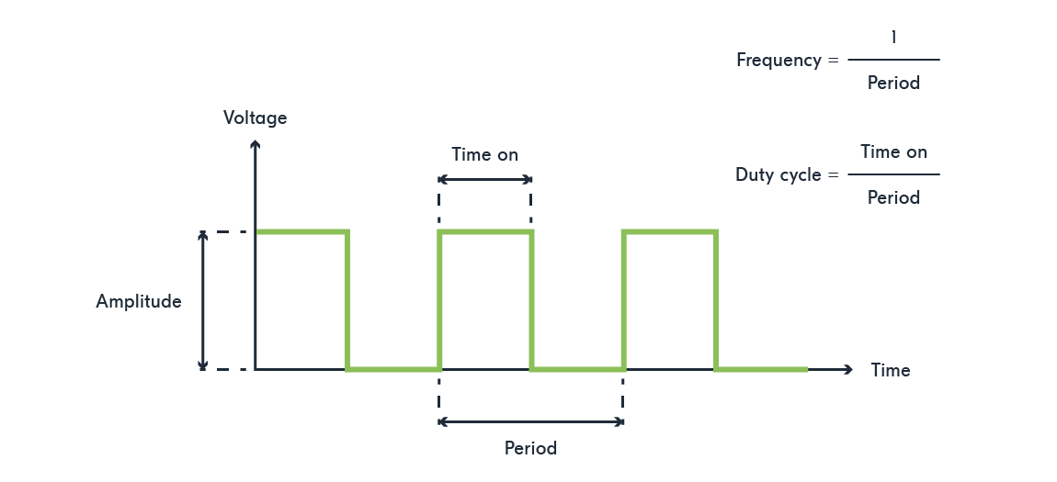
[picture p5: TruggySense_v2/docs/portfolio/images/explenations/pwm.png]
    
    \caption{PWM structure~\cite{Dev2026}.}
\end{figure}
\RmFigWS

\clearpage
\subsection{I2C}
The LLC (Teensy 4.1) contains 3 seperate I²C busses.
Each I²C bus allows one master node and multiple slave nodes to be attach simultaniously.
In our implementation, the LLC will always act as the I²C master.
I²C makes use of two lines: The SDA line (act as the data line) and the SCL line (provide a clock signal so that the modules are in sync).

\RmFigWS
\begin{figure}[h!]
    \centering
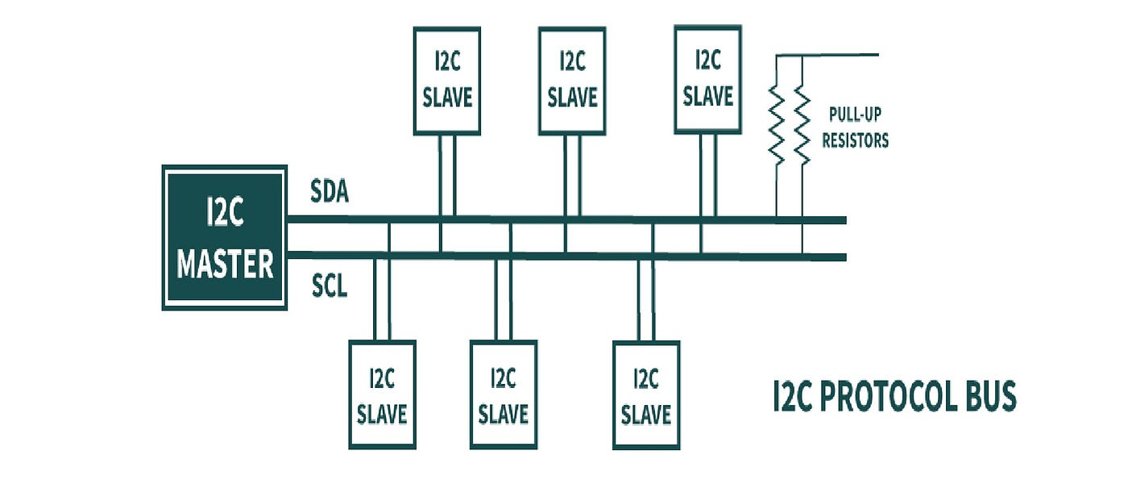
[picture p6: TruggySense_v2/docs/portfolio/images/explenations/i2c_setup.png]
    
    \caption{I²C bus layout~\cite{Ouiyzme2023}.}
\end{figure}
\RmFigWS

The master node will send out:
\RmLstWS
\begin{itemize}
    \item A start bit to initialize the conversation with the slave nodes.
    \item An address frame. All slaves will see this address, but only the slave to which the address belongs will answer.
    \item A bit that indicates if the master nodes wants to send or receive data.
    \item The acknowledgement of the slave.
    \item The data frames (one byte) the were either send or requested by the master node.
    \item Acknowledgement from the recipient.
    \item A stop bit to end the connection.
\end{itemize}
\RmLstWS

\RmFigWS
\begin{figure}[h!]
    \centering
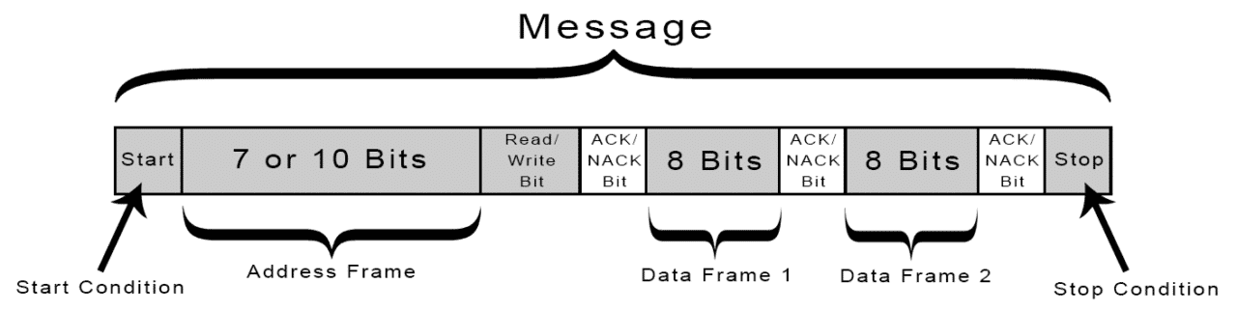
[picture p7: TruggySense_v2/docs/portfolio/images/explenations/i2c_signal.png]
    
    \caption{I²C message layout~\cite{Circuit2016}.}
\end{figure}
\RmFigWS

The standart speed supported by the LLC for I²C is 100kbps (kilo bits per second).
Using different modes this could be increased to 400kbps or 1Mbps.
\subsection{SPI}
The LLC (Teensy 4.1) contains 2 seperate SPI busses.
Each SPI bus allows for one master node and multiple slave nodes.
In our implementation, the LLC will always act as the SPI master.
SPI makes use of four lines:
\RmLstWS
\begin{itemize}
    \item The CS/SS (chip/slave select) line, will indicate with which slave the master will communicate.
          The master will need to provide a CS line for each slave on the same bus.
          It indicates when it wants to communicate with a specific slave, by setting the CS line LOW.
    \item The SCLK/SCK (clock) line, which acts as a reference on which the data is send and to keep all modules in sync.
    \item The MOSI (master out, slave in) line, is used when the master wants to send data to the slave.
    \item The MISO (master in, slave out) line, is used when the master wants to receive data from the slave.
\end{itemize}
\RmLstWS

\clearpage
\ImageComparison
    {SPI layout}
    {spi_layout}
    {{explenations/spi_setup.png}/{Bus layout~\cite{Microcontroller2026}}
    /{explenations/spi_signal.png}/{Signal example~\cite{Rohde2023}}}
\RmFigWS

The LLC has a reliable clock speed of 40MHz.
This means that it has a throughput of 40Mbps.
\subsection{UART}
The LLC (Teensy 4.1) contains 8 seperate UART busses.
Each UART bus allows for two nodes.
UART makes use of two lines: The TX (transmit) line and the RX (receive) line.
Note that the TX pin of node one needs to be connected to the RX pin of node two, and vice versa.

\RmFigWS
\ImageComparison
    {UART layout}
    {uart_layout}
    {{explenations/uart_setup.png}/{Bus layout~\cite{Kelvin2022}}
    /{explenations/uart_signal.png}/{Signal example~\cite{Kelvin2022}}}
\RmFigWS

Most UART modules use the default settings. These are a baud rate of 9600 --corresponding to a transmission speed of 9600 bits per second (bps)-- with an 8N1 configuration.
UART always starts with one start-bit, and the 8N1 notation indicates the following: '8' indicates eight data-bits are send per frame, 'N' indicates that no parity-bit is used, and '1' indicates one stop-bit is used.
This means that every byte needs 10 bits to be send, resulting in a transmission speed of 960 bytes per second (Bps) or a byte period of $\sim$1.04ms.
Both the baud rate and configuration can be changed, but in our implementation only the baud rate will be adjusted to 115200.
\section{Modules}
\subsection{LED}
An led will be added to the logic board, to indicate if the system has initialized correctly.

\RmFigWS
\begin{figure}[h!]
    \centering
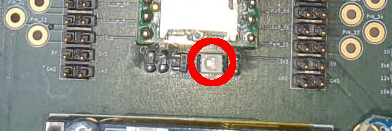
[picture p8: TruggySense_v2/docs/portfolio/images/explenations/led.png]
    
    \caption{Indicator led.}
\end{figure}
\RmFigWS

\clearpage
When this led is:
\RmLstWS
\begin{itemize}
    \item On, it indicates that the initialization is in progress.
    \item Off, it indicates that the initialization has failed.
    \item Toggles, it indicates that the initialization was succesfull and that the schedular is activated.
\end{itemize}
\RmLstWS
\subsection{Motor}
When using the Torox 185, make sure to set the system correctly.

\RmFigWS
\begin{figure}[h!]
    \centering
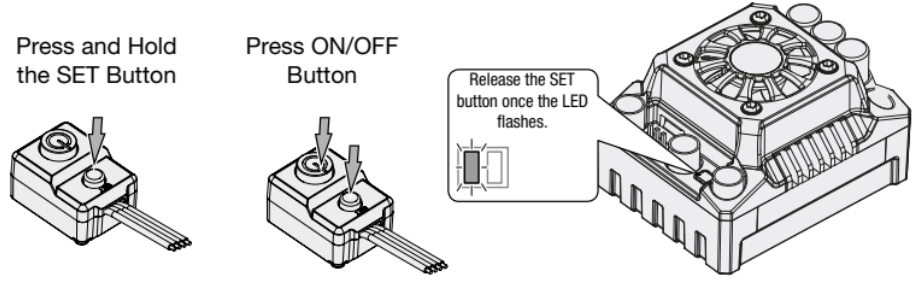
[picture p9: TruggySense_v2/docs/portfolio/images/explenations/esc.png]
    
    \caption{ESC module~\cite{Corally2026}.}
\end{figure}
\RmFigWS

First of all, we need to enable reverse driving.
This is done by pressing and holding both the ON/OFF and SET buttons, until the Green led toggles.
You are now in running mode.
In this mode the system will portray the configuration every 10 seconds using a blinking red led and beep.
The configuration is as follows:
\RmLstWS
\begin{itemize}
    \item 1 blink \rightarrow~Forward with brake.
    \item 2 blink \rightarrow~Forward / Reverse with brake.
\end{itemize}
\RmLstWS
Turn the system off to save the configuration.

To calibrate the system, first press the ON/OFF button.
A green led will blink 4 times, 1 for each LiPo cell it detects\footnote{It will just measure the voltage. If the voltage is above 14.8V, then you should get this effect.}.
Afterwards the red led will toggle constantly until the neutral position is administered.
This is done by providing a 50Hz PWM (20ms period), with an active time of 1500µs (1.5ms).
Once calibrated the led will stop toggling, and any PWM signal with a higher duty-cycle than the neutral position will activate the motor.
\subsection{FlySky}
% Add FlySky connect:   https://www.youtube.com/watch?v=q80QijmQzOI
% Remote Control:       https://youtu.be/JZQoHmLqZYg?si=V70LEDVfeEnfySdj
The first thing to do when using FlySky modules is to bind them.
To start this, on the reciever board, press the "Bind" Button (the button at the edge of the board), while powering on the module.
The led should be blinking quite fast now.
Now on the transitter module, press the "Bind" Button (the button next to the bottom left corner of the screen) and power it on.
The red led on the receiver should now be solid, this means that the modules are bound.
\href{https://www.youtube.com/watch?v=q80QijmQzOI}{Follow \textbf{this video} if needed.}

Now to set the auxilary ports.
The transmitter supports 14 channels that send a value between 1000 and 2000.
The first four channels are locked to the horizontal and vertical movement of the joysticks.
The other channels can be configured as followed:
\RmLstWS
\begin{itemize}
    \item Turn on the transmitter.
    \item Press and hold the "OK" button.
          This should open the menu.
    \item Choose "System setup" by pressing the "OK" button.
    \item Then use the "UP" and "DOWN" buttons to go to the bottom of the list and select "Aux. switches".
    \item Turn on the swithces you want to use.
    \item Press and hold "CANCEL" to save.
    \item Turn off the transmitter.
\end{itemize}

\begin{itemize}
    \item Turn on the transmitter back on.
    \item Press and hold the "OK" button, opening the menu.
    \item Choose "Functions setup".
    \item Scroll down to "Aux. channels".
    \item Use the "UP" and "DOWN" buttons to bind a switch to a channel.
    \item Press and hold "CANCEL" to save.
    \item Turn off the transmitter.
\end{itemize}
\RmLstWS
\href{https://www.youtube.com/watch?v=JZQoHmLqZYg}{Follow \textbf{this video} if needed.}

Note that for this project channel 5 is connected to SWA.
This switch acts as the deadswitch of the entire system.

\RmFigWS
\ImageComparison
    {FlySky system}
    {flysky_system}
    {{explenations/fs_x6b.png}/{Transmitter~\cite{FlySky2016}}
    /{explenations/fs_i6x.png}/{Receiver~\cite{Pete2026}}}
\RmFigWS
\subsection{GPS}
The GPS makes use of a u-blox module.
From this we can conlcude that the system uses the default configuration (baud rate 9600 and config 8N1), and that this can be changed using the \href{https://www.u-blox.com/en/product/u-center}{\textbf{u-center application}}.
The problem is that this application only runs on Windows, and that not all modules allow configuration changes to be saved to the flash.

Still the communication speed of the module needs to be altered since the default settings provide a byte period of $\sim$1.04ms, and the schedular of the system uses synchronous interrupts that repeat every 1ms.
If the communication speed was set to 115200, the byte period would become $\sim$86.81µs, making the schedular less of a problem.
This will be performed during the initialization of the system (before the schedular is activated).
By sending the right byte array the configuration can be altered (this will reset at power down).

The following configuration changes are sent at startup:
\RmLstWS
\begin{itemize}
    \item Disable the GLL, GSA, GSV, and VTG data.
          This data isn't used and therefore can be turned off.
    \item Set the update rate to 10Hz.
          This will provide us with more data.
    \item Set the baud rate to 115200.
\end{itemize}
\RmLstWS
\clearpage
\subsection{Wheel encoders}
The wheel encoders work using asynchronous interrupts.
When these hall-effect sensors detect a magnet they pull the signal line down.
A counter then keeps track of how many magnets have passed, and using the following formulas, the wheel can be determined:
\begin{align}
    t_\Delta &= \frac{t_1 - t_0}{1000} \\
    f_p      &= \frac{1}{t_\Delta} \\
    f_w      &= \frac{f_p \cdot n_p}{N_\text{mag}} \\
    \omega_w &= f_w \cdot 60 \\
    t_\Delta &= \frac{t_1 - t_0}{1000} \\
    f_w      &= \frac{1}{t_\Delta} \cdot \frac{n_p}{N_\text{mag}}\\
    \omega_w &= f_w \cdot 60
\end{align}
With $t\Delta$ representing the periode of the pulses (in seconds), $f_p$ the frequency of the pulse (in Herz), 
$X$ the number of magnets installed on the encoder ring, $\omega_w$ the rotational speed (in revolutions per second),
$d$ the diameter (in meters), $v$ the velocity (kilometer per hour), and $n_p$ denoting the number of pulses detected~\cite{Elsermans2025}.

\RmFigWS
\begin{figure}[h!]
    \centering
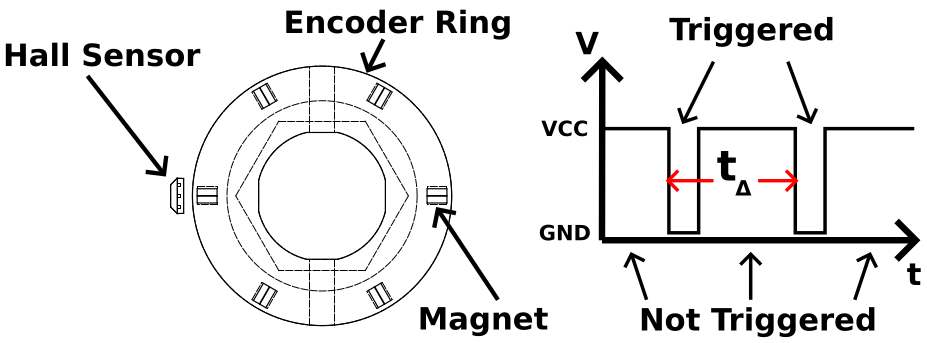
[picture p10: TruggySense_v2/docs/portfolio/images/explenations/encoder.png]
    
    \caption{Encoder ring structure~\cite{Elsermans2025}.}
\end{figure}
\RmFigWS
\subsection{IMU}
The IMU works over I²C and collects 9-DoF information, inlcuding 3-DoF accelerometer data, 3-DoF gyroscope data, and 3-DoF magnetometer data.
Each of the 3-DoF data sets are reperesented by a x, y, and z number.
These 9-DoF values can be converted to quaternion\footnote{A quaternion is another way of representing 3D rotation.} using a Mahony filter.
These are the steps:
\begin{enumerate}
    \item Timing & Sample Frequency:
        \begin{align}
            t_\Delta & = \frac{t_1 - t_0}{10^6} \\
            f_s      & = \frac{1}{t_\Delta}
        \end{align}
        With $f_s$ the sample frequency (in Herz).
    \item Normalise accelerometer data:
        \begin{align}
            a_{norm} & = \frac{1}{\sqrt{a_x^2 + a_y^2 + a_z^2}} \\
            a_x      & = a_x \cdot a_{norm} \\
            a_y      & = a_y \cdot a_{norm} \\
            a_z      & = a_z \cdot a_{norm}
        \end{align}
        With $a$ representing the normalized acceleration vector.
    \item Normalise magnetometer data:
        \begin{align}
            m_{norm} & = \frac{1}{\sqrt{m_x^2 + m_y^2 + m_z^2}}\\
            m_x      & = m_x \cdot m_{norm} \\
            m_y      & = m_y \cdot m_{norm} \\
            m_z      & = m_z \cdot m_{norm}
        \end{align}
        With $m$ representing the normalized magnetometer vector.
    \item Reference the data to the direction of Earth's magnetic field:
        \begin{align}
            h_x &= 2\!\left[m_x\!\left(\tfrac{1}{2} - q_2^2 - q_3^2\right) + m_y(q_1 q_2 - q_0 q_3) + m_z(q_1 q_3 + q_0 q_2)\right] \\
            h_y &= 2\!\left[m_x(q_1 q_2 + q_0 q_3) + m_y\!\left(\tfrac{1}{2} - q_1^2 - q_3^2\right) + m_z(q_2 q_3 - q_0 q_1)\right] \\
            b_x &= \sqrt{h_x^2 + h_y^2} \\
            b_z &= 2\!\left[m_x(q_1 q_3 - q_0 q_2) + m_y(q_2 q_3 + q_0 q_1) + m_z\!\left(\tfrac{1}{2} - q_1^2 - q_2^2\right)\right]
        \end{align}
        With $h$ representing the magnetic field vector, and $b$ Earth's magnetic field vector.
    \item Estimated direction of gravity and magnetic field
        \begin{align}
            \tfrac{1}{2}v_x &= q_1 q_3 - q_0 q_2 \\
            \tfrac{1}{2}v_y &= q_0 q_1 + q_2 q_3 \\
            \tfrac{1}{2}v_z &= q_0^2 - \tfrac{1}{2} + q_3^2 \\[6pt]
            \tfrac{1}{2}w_x &= b_x\!\left(\tfrac{1}{2} - q_2^2 - q_3^2\right) + b_z(q_1 q_3 - q_0 q_2) \\
            \tfrac{1}{2}w_y &= b_x(q_1 q_2 - q_0 q_3) + b_z(q_0 q_1 + q_2 q_3) \\
            \tfrac{1}{2}w_z &= b_x(q_1 q_3 + q_0 q_2) + b_z\!\left(\tfrac{1}{2} - q_1^2 - q_2^2\right)
        \end{align}
        With $v$ representing the gravity vector, and $w$ estimated magnetic field vector.
    \item Find the error (Cross Product):
        \begin{align}
            \tfrac{1}{2}e_x &= (a_y \cdot \tfrac{1}{2}v_z - a_z \cdot \tfrac{1}{2}v_y) + (m_y \cdot \tfrac{1}{2}w_z - m_z \cdot \tfrac{1}{2}w_y) \\
            \tfrac{1}{2}e_y &= (a_z \cdot \tfrac{1}{2}v_x - a_x \cdot \tfrac{1}{2}v_z) + (m_z \cdot \tfrac{1}{2}w_x - m_x \cdot \tfrac{1}{2}w_z) \\
            \tfrac{1}{2}e_z &= (a_x \cdot \tfrac{1}{2}v_y - a_y \cdot \tfrac{1}{2}v_x) + (m_x \cdot \tfrac{1}{2}w_y - m_y \cdot \tfrac{1}{2}w_x)
        \end{align}
        With $e$ representing the error vector.
    \item Apply integral feedback:
        \begin{align}
            I_x &\mathrel{+}= \frac{2K_i \cdot \tfrac{1}{2}e_x}{f_s} \\
            g_x &\mathrel{+}= I_x \\
            I_y &\mathrel{+}= \frac{2K_i \cdot \tfrac{1}{2}e_y}{f_s} \\
            g_y &\mathrel{+}= I_y \\
            I_z &\mathrel{+}= \frac{2K_i \cdot \tfrac{1}{2}e_z}{f_s} \\
            g_z &\mathrel{+}= I_z
        \end{align}
        With $I$ representing the integral feedback accumulation, and $g$ representing the gyroscope vector.
    \item Apply proportional feedback: 
        \begin{align}
            g_x &\mathrel{+}= 2K_p \cdot \tfrac{1}{2}e_x \\
            g_y &\mathrel{+}= 2K_p \cdot \tfrac{1}{2}e_y \\
            g_z &\mathrel{+}= 2K_p \cdot \tfrac{1}{2}e_z
        \end{align}
    \item Add the new values to the quaternions:
        \begin{align}
            q_0 &\mathrel{+}= \left(-q_1 g_x - q_2 g_y - q_3 g_z\right)\frac{\Delta t}{2} \\
            q_1 &\mathrel{+}= \left(\phantom{-}q_0 g_x + q_2 g_z - q_3 g_y\right)\frac{\Delta t}{2} \\
            q_2 &\mathrel{+}= \left(\phantom{-}q_0 g_y - q_1 g_z + q_3 g_x\right)\frac{\Delta t}{2} \\
            q_3 &\mathrel{+}= \left(\phantom{-}q_0 g_z + q_1 g_y - q_2 g_x\right)\frac{\Delta t}{2}
        \end{align}
\end{enumerate}
With the constatnts $\Delta t = \frac{1}{f_s}, \qquad 2K_p = 2.0, \qquad 2K_i = 0.005$.

These quaternions can then be converted to Euler/orientation angles, using the following code:
\begin{enumerate}
    \item Quaternion Normalisation
        \begin{align}
            r         &= \frac{1}{\sqrt{q_0^2 + q_1^2 + q_2^2 + q_3^2}} \\
            \hat{q}_i &= q_i \cdot r \quad \text{for } i \in \{0, 1, 2, 3\}
        \end{align}
    \item Euler Angles from Quaternion
        \begin{align}
            \phi   &= \frac{360}{2\pi}\arctan\!\left(\frac{2(q_0 q_1 + q_2 q_3)}{1 - 2(q_1^2 + q_2^2)}\right) \\[6pt]
            \theta &= \frac{360}{2\pi}\arcsin\!\left(2(q_0 q_2 - q_3 q_1)\right) \\[6pt]
            \psi   &= \frac{360}{2\pi}\arctan\!\left(\frac{2(q_0 q_3 + q_1 q_2)}{1 - 2(q_2^2 + q_3^2)}\right)
        \end{align}
\end{enumerate}
With the constatnts $\frac{360}{2\pi} = \frac{180}{\pi} \approx 57.296 \quad \text{(radians to degrees)}$.

The orientation angles of the modules are always noted on top off them.
Make sure that they are in the correct orientation compared to the chassis.

\RmFigWS
\begin{figure}[h!]
    \centering
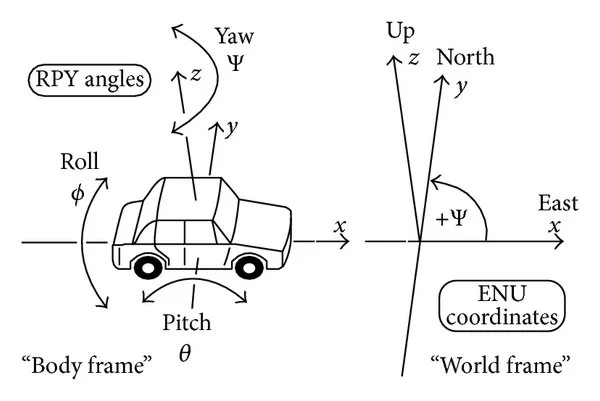
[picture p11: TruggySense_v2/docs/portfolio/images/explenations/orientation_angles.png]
    
    \caption{Orientation angles~\cite{Yi2015}.}
\end{figure}
\clearpage
\subsection{SD-card}
The LLC provides SD-card intregation, thus we can implement persistent data.
The default way to store the gathered data is in a .bin file.
To study the data, support for both .csv and .json files has been added.
The .json files are needed by the matlab scripts that generate the graphs later used.

Make sure that the SD-cards are formated in NTFS.
\subsection{nRF24L01}
This module makes use of the SPI protocol.
The thing to look out for is that it has both a CS and CE pin.
Neither of these pins need to be connected to the CS pin of the LLC, they only have to be connected to a PWM pin.
Note that in the code these pins have to be altered to match the hardware.

This project only got the receiver module to work, while it was attached to an Arduino UNO.
Here is the sketch that was used:
\begin{lstlisting}[style=platformio]
/*
* Arduino Wireless Communication Tutorial
*       Example 1 - Receiver Code
*                
* by Dejan Nedelkovski, www.HowToMechatronics.com
* 
* Library: TMRh20/RF24, https://github.com/tmrh20/RF24/
*/

#include <SPI.h>
#include <nRF24L01.h>
#include <RF24.h>

RF24 radio(7,8); // CE, CSN 7, 8

const byte address[6] = "00001";

void setup() {
  Serial.begin(115200);
  pinMode(LED_BUILTIN, OUTPUT);
  digitalWrite(LED_BUILTIN, LOW);
  
  while (!Serial) { }
  Serial.println("Receiver on");
  digitalWrite(LED_BUILTIN, HIGH);
  
  if (!radio.begin()) {
    Serial.println("radio.begin() FAILED — SPI not working");
    while(1);
  }
  if (!radio.isChipConnected()) {
    Serial.println("nRF24L01 not detected! Check wiring/power.");
    // while (1);  // halt
  } else
    Serial.println("Chip connected OK");
  radio.openReadingPipe(0, address);
  radio.setPALevel(RF24_PA_MIN);
  radio.setChannel(76);
  //radio.setAutoAck(false);
  //Serial.println("=== Radio Config ===");
  //radio.printDetails();   // dumps all registers
  //Serial.println("=== Listening ===");
  radio.startListening();
}

void loop() {
  // Serial.println("Listening...");  // temporary debug line
  /*if (radio.available()) {
    char text[32] = "";
    radio.read(&text, sizeof(text));
    Serial.println(text);
  }*/
  if (radio.available()) {
    uint8_t chunk[32] = {0};
    radio.read(&chunk, sizeof(chunk));
    
    uint8_t chunkIndex = chunk[0];
    if (chunkIndex == 0) Serial.println();
    Serial.print("Read chunk ");
    Serial.print(chunkIndex);
    Serial.print(":\t");
    
    for (int j = 0; j < 32; j++) {
      if (chunk[j] < 0x10) Serial.print("0");
      Serial.print(chunk[j], HEX);
      Serial.print(" ");
    }
    
    Serial.println();
  }
}
\end{lstlisting}

\chapter{Prototype Design}          % ---------------------- Prototype design ----------------------
\section{Logical design}
\RmFigWS
\begin{figure}[h!]
    \caption{TruggySense logic interaction between modules}
    \centering
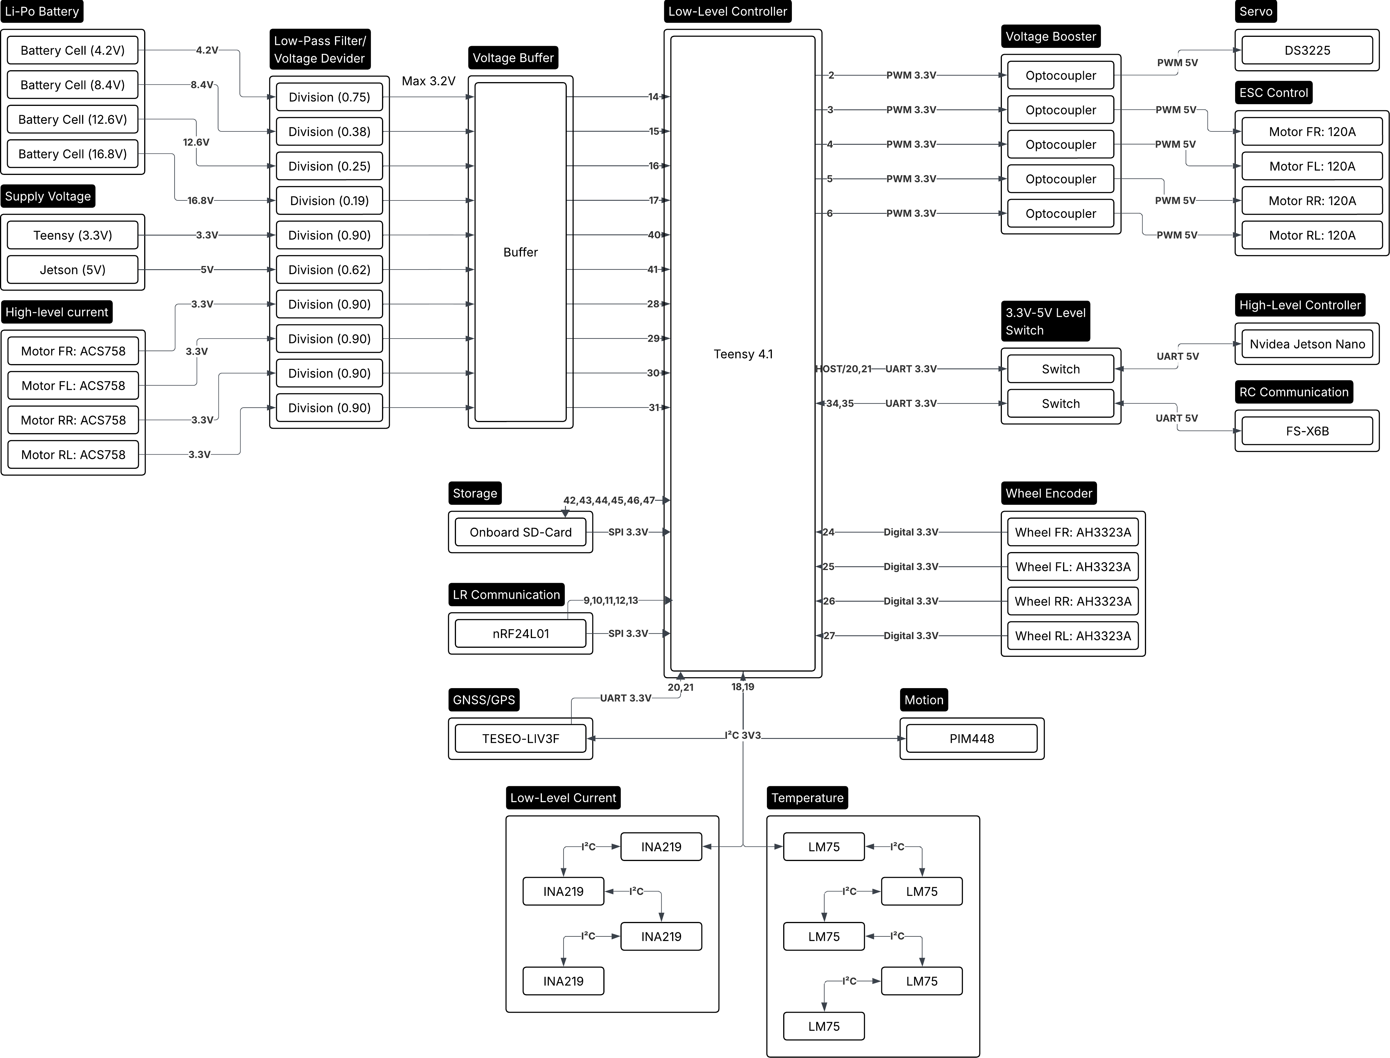
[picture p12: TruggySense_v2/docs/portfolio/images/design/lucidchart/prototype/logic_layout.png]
    
\end{figure}
\newpage
\section{Power design}
\RmFigWS
\begin{figure}[h!]
    \caption{TruggySense power interaction between modules}
    \centering
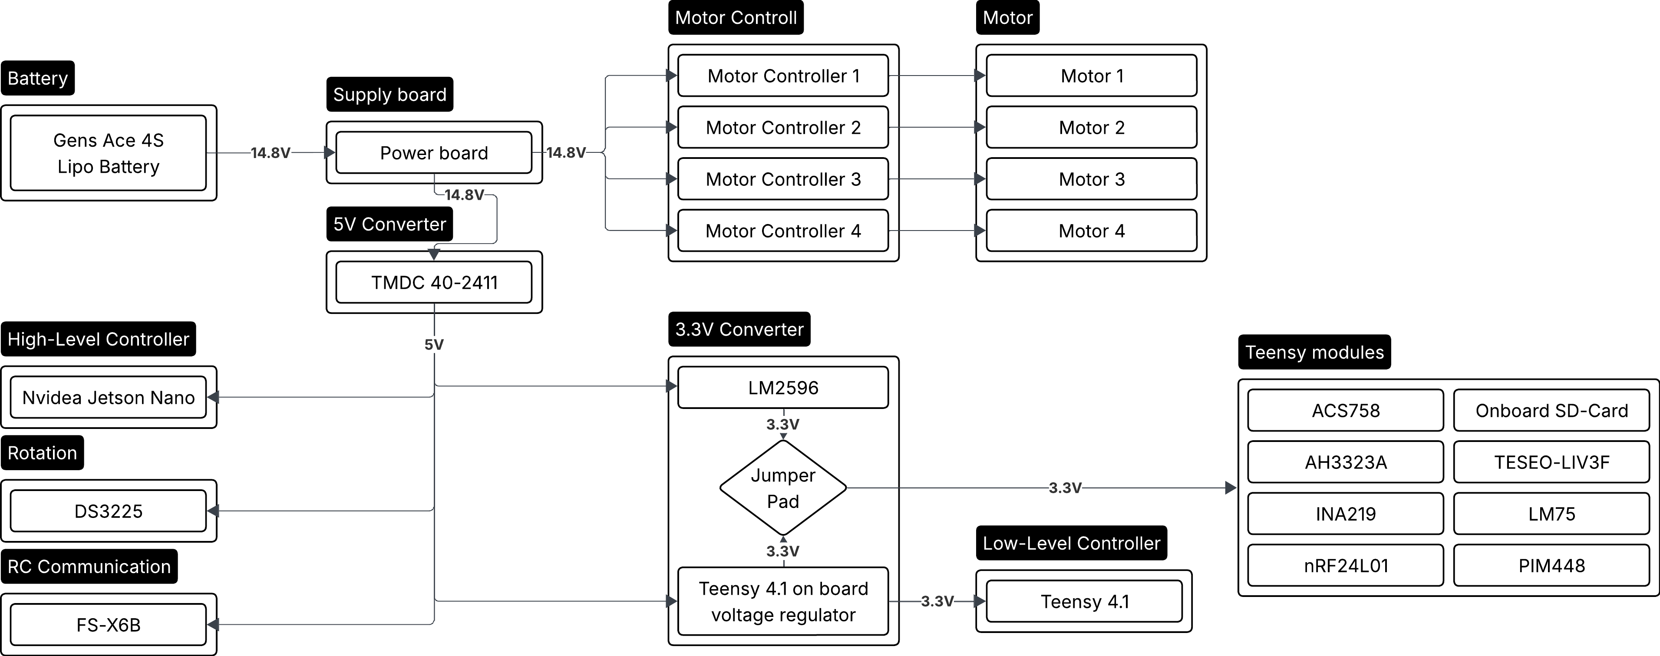
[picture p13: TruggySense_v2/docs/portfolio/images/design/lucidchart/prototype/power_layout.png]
    
\end{figure}
\RmFigWS
\section{KiCAD}
KiCAD 9.0 was used to design the PCBs.
The guide below will show how to install KiCAD and showcase the base functionalities.
\subsection{Guide}
\label{sec:kicad_guide}
\subsubsection{Install KiCAD}
The installation for Windows can be found using \href{https://www.kicad.org/download/windows/}{this link}.

The installation for Linux (Debian and Ubuntu) can be done using the following commands:
\begin{lstlisting}[style=cmd]
# Install KiCad:
    sudo apt update && sudo apt install -t kicad kicad-symbols kicad-footprints kicad-packages3d

# Verify success:
    kicad --version
\end{lstlisting}
\RmLstWS\RmTabWS
\subsubsection{Add component library}
% Logic for the row count
\newcount\TotalRows                 % Create a CSV row variable
\TotalRows=0                        % Set it to 0
\csvreader[head to column names]{./databases/design/download.csv}{}{
    \global\advance\TotalRows by 1  % Increment for every CSV row
}
%\the\TotalRows                      % Show the row count
% Half row rounded up
\newcount\HalfRow                   % Create a half row variable
\HalfRow=\numexpr\TotalRows/2\relax
%\the\HalfRow                        % Show the row count
% Next row
\newcount\NextRow
\NextRow=\numexpr\HalfRow+1\relax
%\the\NextRow                        % Show the row count

\Needspace{10\baselineskip}
\begin{table}[h!]
    \centering
    \caption{Component usage overview}
    \begin{minipage}[t]{0.47\textwidth}
        \centering
        \begin{tabular}{p{0.47\textwidth} p{0.47\textwidth}}
            \toprule
                \textbf{Component} & \textbf{Used in} \\
            \midrule
                \csvreader[
                    head to column names,
                    late after line=\\,
                    range=0-\HalfRow,
                ]{./databases/design/download.csv}{}{
                    \href{\CompURL}{\Component} & \UsedIn
                }
            \bottomrule
        \end{tabular}
    \end{minipage}
    \hfill
    \begin{minipage}[t]{0.47\textwidth}
        \centering
        \begin{tabular}{p{0.47\textwidth} p{0.47\textwidth}}
            \toprule
                \textbf{Component} & \textbf{Used in} \\
            \midrule
                \csvreader[
                    head to column names,
                    late after line=\\,
                    range=\NextRow-\TotalRows,
                ]{./databases/design/download.csv}{}{
                    \href{\CompURL}{\Component} & \UsedIn
                }
            \bottomrule
        \end{tabular}
    \end{minipage}
\end{table}
\RmTabWS
\begin{enumerate}[label*=\arabic*., nosep]
    \item From the main project window.
    \item Click the "preferences" tab.
    \item Click "Manage Symbols Library".
    \begin{enumerate}[label*=\arabic*., nosep]
        \item Click "Add existing library to the table" (folder-icon on the bottom left).
        \item Go to the \verb|.kicad_sym| file and select it.
        \item Click "OK".
    \end{enumerate}
    \item Click "Manage Footprint Library".
    \begin{enumerate}[label*=\arabic*., nosep]
        \item Click "Add existing library to the table" (folder-icon on the bottom left).
        \item Go to the \verb|.kicad_sym| file and select its folder.
        \item Click "OK".
    \end{enumerate}
    \item Open the schematic and press 'A'.
    \item Choose the symbol and dropt it into the schematic.
    \item Double click on the component.
    \item Change the footprint.
\end{enumerate}

Add shortcuts to the right files to make your life easier.
For Debian users this can be done as follows:
\begin{lstlisting}[style=cmd]
# Connect the repo symbol directory to that of the installation:
    ln -s ~/<path_to_repo>/TruggySense/cad/KiCAD/library ~/.local/share/kicad/9.0/symbols/
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

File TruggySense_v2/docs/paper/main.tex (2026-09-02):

\documentclass[conference,a4paper]{IEEEtran}
\IEEEoverridecommandlockouts

% Some very useful LaTeX packages include:
% (uncomment the ones you want to load)
\usepackage[utf8]{inputenc}

% *** CITATION PACKAGES ***
%
\usepackage{cite}

% *** GRAPHICS RELATED PACKAGES ***
%
\usepackage[pdftex]{graphicx}
% declare the path(s) where your graphic files are
\graphicspath{{./Images/}}
% and their extensions so you won't have to specify these with
% every instance of \includegraphics
% \DeclareGraphicsExtensions{.PDF,.jpeg,.png}
\makeatletter
\newcommand\footnoteref[1]{\protected@xdef\@thefnmark{\ref{#1}}\@footnotemark}
\makeatother
% https://tex.stackexchange.com/a/35044

% *** MATH PACKAGES ***
%
\usepackage[cmex10]{amsmath}
\usepackage[detect-all]{siunitx}

% *** SPECIALIZED LIST PACKAGES ***
%
\usepackage{algorithmic}

% *** ALIGNMENT PACKAGES ***
%
%\usepackage{array}

%\usepackage{mdwmath}
%\usepackage{mdwtab}

% IEEEtran contains the IEEEeqnarray family of commands that can be used to
% generate multiline equations as well as matrices, tables, etc., of high
% quality.

%\usepackage{eqparbox}

% *** SUBFIGURE PACKAGES ***
%\usepackage[tight,footnotesize]{subfigure}

%\usepackage[caption=false]{caption}
%\usepackage[font=footnotesize]{subfig}

\usepackage[caption=false,font=footnotesize]{subfig}
\usepackage{tablefootnote}
\usepackage{capt-of}
\usepackage{needspace}
\usepackage[flushleft]{threeparttable}

% *** MATH PACKAGES ***
\usepackage{amsmath}

\DeclareMathOperator{\arctantwo}{arctan2}
\DeclareMathOperator{\sinsq}{sin^2}

% *** FLOAT PACKAGES ***
%
%\usepackage{fixltx2e}

%\usepackage{stfloats}

%\fnbelowfloat

% *** PDF, URL AND HYPERLINK PACKAGES ***
%
\usepackage[obeyspaces]{url}
\usepackage{xurl}

% Advanced table environment
\usepackage{booktabs}

% correct bad hyphenation here
\hyphenation{op-tical net-works semi-conduc-tor}

% Create separator commands:
\let\oldsection\section
\renewcommand{\section}[1]{
  \setlength{\parskip}{0em}
  \setlength{\parindent}{0pt}
  \oldsection{#1}
}

\let\oldsubsection\subsection
\renewcommand{\subsection}[1]{
  \setlength{\parskip}{0.5em}
  \setlength{\parindent}{0pt}
  \oldsubsection{#1}
}

\newcommand{\ParagraphSeperator}{
  \setlength{\parskip}{0em}
  \setlength{\parindent}{10pt}
}

\begin{document}

% paper title
% can use linebreaks \\ within to get better formatting as desired
\title{TruggySense: Hardware and Firmware Redesign for Reproducibility}

% author names and affiliations
\author{
	\IEEEauthorblockN{
		Thomas Kramp\IEEEauthorrefmark{1}, 
		Jan Steckel\IEEEauthorrefmark{1} \IEEEauthorrefmark{2}
	}
	\IEEEauthorblockA{
		\IEEEauthorrefmark{1}Faculty of Applied Engineering: Department of \mbox{Electronics-ICT} - University of Antwerp, Antwerp, Belgium, \\
		\IEEEauthorrefmark{2}Flanders Make Strategic Research Centre, Lommel, Belgium
	}
	\thanks{Master's thesis to obtain the diploma 
			Master of Science in Electronics and Information and Communication Technology. Academic year \mbox{2024-2025}.
			This Master's thesis is an examination document that may not have been corrected for any errors in its final version. 
			Reproduction and copying of this publication or parts thereof are prohibited without the prior written consent of 
			both the supervisor(s) and the author(s). For requests or information regarding the publishing and/or use and/or 
			realization of parts of this publication, please contact the university at which the author is registered.
			Prior written consent of the supervisor(s) is also required for the use of the (original) methods, products, 
			circuits and programmes described in this thesis for industrial or commercial use, and for the submission of this 
			publication for participation in scientific prizes or competitions.

			This document has been assessed by supervisor(s) and/or supervisors in accordance with the faculty 
			Master's thesis regulations.}
}

% make the title area
\maketitle

\ParagraphSeperator
\begin{abstract}
%\boldmath
In this paper a redesign of both hardware and firmware regarding the TruggySense, an off-road Data Acquisition System (DAQ) implemented on a 1/8 Remote-Controlled Vehicle (RCV), is presented.
The system is intended to provide practical and consistent data to enable academic learning opportunities surrounding Advanced Driving Assistance Systems (ADAS).
The TruggySense was able to produce insight into itself, as an RCV, by providing real-time telemetry data and performing four experiments that replicate real-world vehicle behavior~\cite{Elsermans2025}.
The redesign reaffirms this while streamlining its assembly and simplifying the process that allows for future modifications.
\end{abstract}

\ParagraphSeperator
\begin{keywords}
Remote-controlled vehicles, Data acquisition systems
\end{keywords}

\section{Introduction}
\ParagraphSeperator
The interest in autonomous vehicles (AV) has been growing over the past decades, for both commercial and military applications~\cite{Algahtani2019}.
However, research towards developing cost-effective AVs is limited~\cite{Brown2022, Baumann2024}, as it usually focuses on urban environments.
Using smaller-scale models is a more cost-effective method~\cite{Li2024}, and enables the testing and validation of the algorithms and techniques that can later be implemented on their full-scaled counterparts.
These vehicles use both RADAR and LiDAR technology to perceive their surroundings, making decisions based on that data~\cite{Loetscher2023}.

\ParagraphSeperator
Nevertheless, numerous external factors influence a vehicle while it is being operated, prompting the question of why there is limited research surrounding Advanced Data Acquisition Systems (ADAS), compared to that of sensing the environment.
The TruggySense was the first step towards developing such a system with, as its main focus, a real-time Data Acquisition System (DAQ) that could then be used as the foundation for the ADAS~\cite{Elsermans2025}.
This would, in turn, lead to research possibilities for both students and researchers in cyber-physical systems, embedded systems, signal, and AV development.

\setlength{\parskip}{0em}
\setlength{\parindent}{10pt}
Unfortunately, the TruggySense has its limitations:
It does not support Individual Wheel Drive (IWD), such as measuring the individual motor currents or providing individual Electronic Speed Control (ESC).
It contains neither reverse polarity protection nor hardware redundancy, making it less suitable for safety-critical systems.
An attempt was also made to implement the Robot Operating System 2 (ROS2) --which, despite its known latency issues, is a well-researched middleware for AVs~\cite{Horváth2024}-- on the High Level Controller (HLC), though this was never fully realized.
However, its greatest hindrance lies in its fault-prone assembly.
The TruggySense is comprised of perfboards and loose wires (as seen in Fig.~\ref{fig:truggysense_v1_assembly}), leading to a high possibility of creating errors.
Thus, a full hardware redesign is required. 

\begin{figure}[!t]
	\centering
	
	\caption{The original TruggySense assembly~\cite{Elsermans2025}.}
	\label{fig:truggysense_v1_assembly}
\end{figure}

\section{Hardware architecture}
\ParagraphSeperator
The original TruggySense utilizes the existing Team Corally Kagama 1/8 RCV platform as a basis, on which both a High Level Controller (HLC) and Low Level Controller (LLC) are placed.
Additionally, numerous sensors and actuators were attached, which could reliably acquire data at high speeds whilst controlling the existing modules of the platform.
These actuators and sensors communicate with the LLC (as seen in Fig.~\ref{fig:truggysense_v2_hardware_architecture}); while the HLC communicates with both LiDAR and RADAR modules\footnote{All implementations regarding the HLC are part of a separate thesis, and thus are not implemented.}.

\begin{figure}[!t]
	\centering
	
	\caption{
		An abstract block diagram that represents the TruggySense V2 hardware architecture. 
		This depicts the LLC as the DAQ, gathering data from all the sensors, while controlling the peripherals of the RCV unit.
	}
	\label{fig:truggysense_v2_hardware_architecture}
\end{figure}

\ParagraphSeperator
Fig.~\ref{fig:truggysense_v2_below_base_plate_assembly} displays the components that were mounted to the base of the Kagama frame.
The only modification made, compared to the first version of the TruggySense (TruggySense V1), is the replacement of temperature sensors.

\begin{figure}[!t]
	\centering
	% https://imageonline.io/add-arrow/
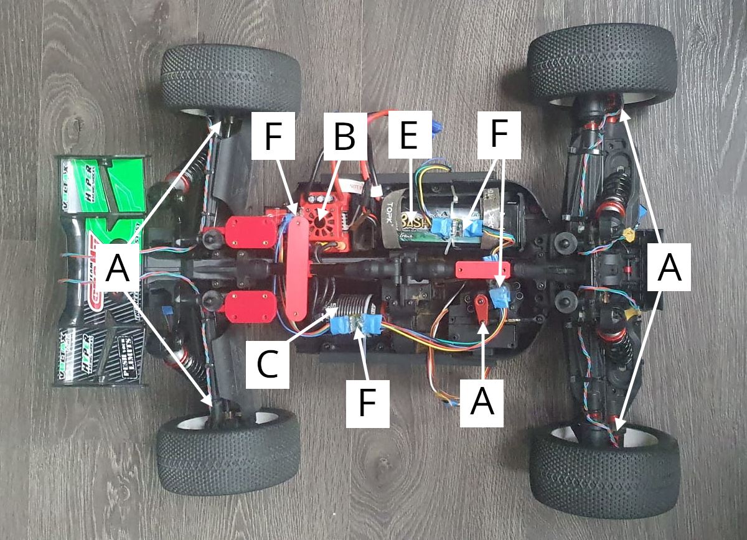
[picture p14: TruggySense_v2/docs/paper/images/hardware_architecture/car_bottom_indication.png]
	
	\caption{
		The hardware layout secured to the chassis of the Corally Kagama, without the base plate mounted, with:
		(A) The wheel encoders,
		(B) The ESC that controls the motor, provided by the Kagama RCV,
		(C) The brushless motor, provided by the Kagama RCV,
		(D) The steering servo,
		(E) The battery pack,
		(F) Various temperature sensors, on a custom-made PCB, daisy-chained together.
	}
	\label{fig:truggysense_v2_below_base_plate_assembly}
\end{figure}

\ParagraphSeperator
Fig.~\ref{fig:truggysense_v2_above_base_plate_assembly} shows the components that were mounted onto the base plate, which in turn is secured to the Kagama frame.
Multiple alterations have been made, compared to the TruggySense V1, including: 
(Fig.~\ref{fig:truggysense_v2_above_base_plate_assembly}.D) The 5V DC-DC converter being replaced by its 40W counterpart, due to the HLC demanding 3A under load;
(Fig.~\ref{fig:truggysense_v2_above_base_plate_assembly}.E) The supply board being separated from the logic board;
(Fig.~\ref{fig:truggysense_v2_above_base_plate_assembly}.H) The GPS being replaced\footnote{The new module was not intended to be used by the prototype. Since there was no connector nor mounting holes provided on the logic board, a separate casing was printed and mounted to the HLC.}.
													        Both the old and new GPS modules are u-blox modules that utilize NMEA-0183 messages\footnote{NMEA-0183 is a serial protocol that works in simplex mode~\cite{Langley1995}.}, thus the new module should be compatible with the old code;
(Fig.~\ref{fig:truggysense_v2_above_base_plate_assembly}.N) A cooling fan being added, due to the HLC significantly heating up, even when not under load;
(Fig.~\ref{fig:truggysense_v2_logic_prototype}.B) The low-Ampere sensors being replaced by their Inter-Integrated Circuit (I2C)\footnote{I2C is a two-wire serial communication protocol using a serial data line (SDA) and a serial clock line (SCL), to allow multiple devices to communicate over the same bus~\cite{Wu2022}.} counterpart.
												  This adds the possibility of redundancy, since the I2C variant allows up to 16 addresses on the same bus, compared to the old module that needs an Analog-to-Digital Conversion (ADC) pin for each module.

\begin{figure}[!t]
    \centering
	% https://imageonline.io/add-arrow/
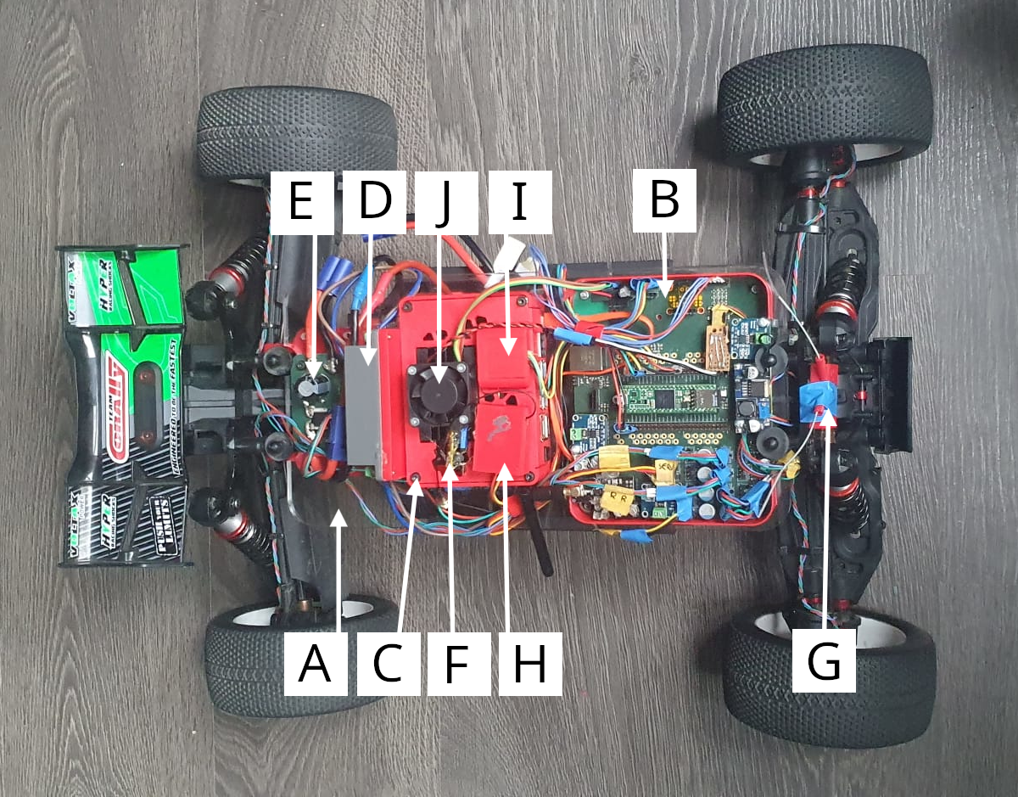
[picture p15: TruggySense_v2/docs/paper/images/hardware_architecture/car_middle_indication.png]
	
    \caption{
		The hardware layout mounted on top of the chassis of the Corally Kagama, utilizing the base plate, with:
		(A) The mounting plate,
		(B) The logic board,
		(C) The HLC,
		(D) The TMDC 40-2411 5V DC-DC 8A converter,
		(E) The supply board,
		(F) The dedicated temperature sensor for the HLC,
		(G) A FlySky X6B, used as the receiver for the remote,
		(H) The GNSS/GPS,
		(I) The 9-DOF IMU unit,
		(J) A 40×40mm fan, used to cool the HLC.
	}
	\label{fig:truggysense_v2_above_base_plate_assembly}
\end{figure}

\ParagraphSeperator
Fig.~\ref{fig:truggysense_v2_cover_assembly} displays the components that were attached to the lid of the Kagama.
The GPS antenna is placed on top of the lid to improve the signal strength (Fig.~\ref{fig:truggysense_v2_cover_assembly}.A).

\begin{figure}[!t]
	\centering
	% https://imageonline.io/add-arrow/
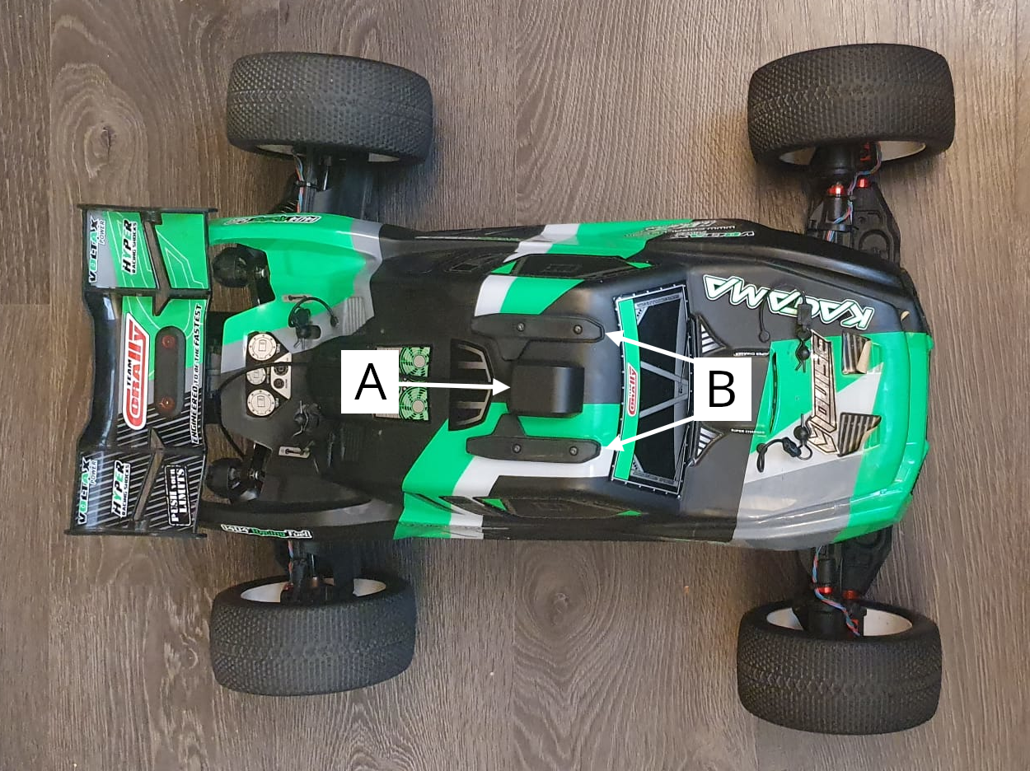
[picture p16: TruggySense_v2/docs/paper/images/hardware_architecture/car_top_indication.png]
	
	\caption{
		The hardware layout attached to the cover of the Corally Kagama, with:
		(A) The GPS antenna, attached using magnets below the cover,
		(B) Mounting brackets that hold the reflector, a folded piece of aluminum foil, to the inside of the roof of the cover.
	}
	\label{fig:truggysense_v2_cover_assembly}
\end{figure}

\subsection{PCB configuration}
\ParagraphSeperator
There are three custom-made PCBs used in this project: The logic board (Fig.~\ref{fig:truggysense_v2_logic_prototype}), the supply board (Fig.~\ref{fig:truggysense_v2_supply_prototype}), and the temperature sensor board (Fig.~\ref{fig:truggysense_v2_temperature_prototype}).
To reduce the assembly complexity, almost all modules and components are mounted directly onto the logic board, except for when this is not possible or logical, such as with the ESC, resulting in a connector being provided on the logic board.
Thus, justifying why the temperature sensors need their own PCB, since they must be affixed to their respective modules or components.

\ParagraphSeperator
The supply board is disconnected from the logic board to reduce the noise generated by the return current of the motor. 
A TMDC 40-2411 is placed between them, providing over-voltage protection and mitigating the effects of voltage and current fluctuations caused by battery discharge. 
Additionally, it offers short-circuit protection by limiting the output upon detection of a short circuit. 
Nevertheless, reverse polarity protection cannot be confirmed, since this claim is only made by third-party distributors and is absent from the official documentation.

\begin{figure}[!t]
    \centering
    % https://imageonline.io/add-arrow/
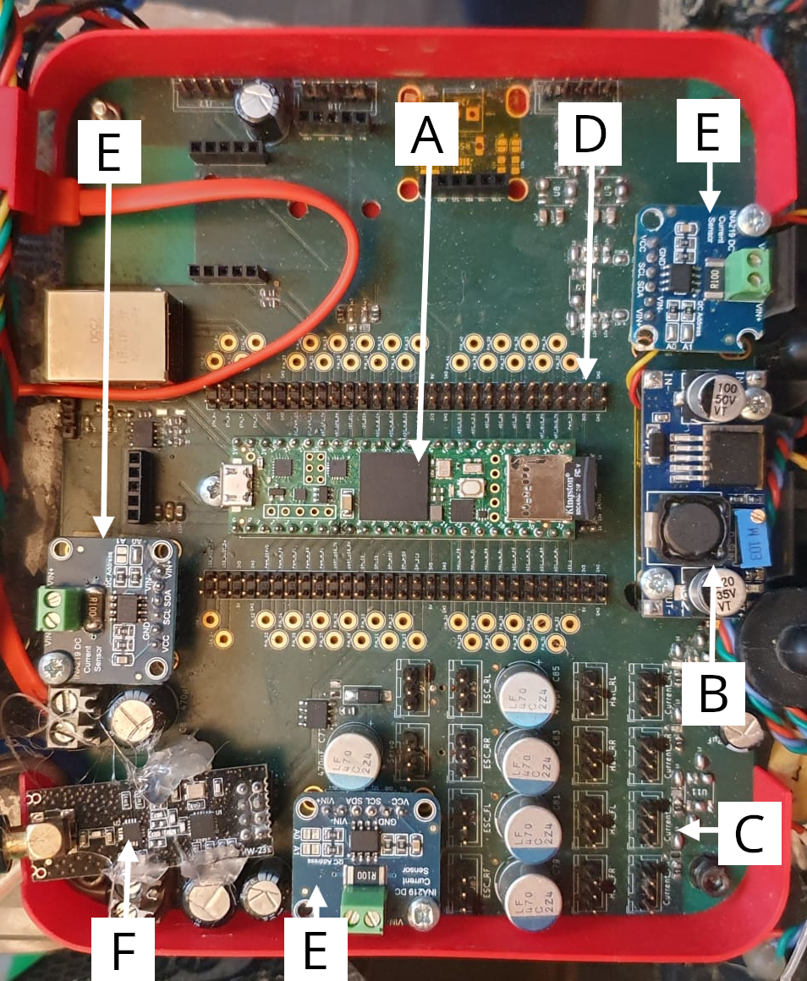
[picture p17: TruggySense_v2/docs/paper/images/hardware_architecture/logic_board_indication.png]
    
    \caption{
        The prototype logic board, with:
        (A) Teensy 4.1 as the LLC,
        (B) The LM2596\protect\stepcounter{footnote}\protect\footnotemark[\value{footnote}] 3.3V DC-DC step-down converter,
        (C) Connectors for IWD sensors and actuators, such as the high-ampere sensors, wheel encoders, and ESC for the motors --with four pin-headers for each--,
        (D) Double-rowed pin headers, connected directly to the pins of the LLC, for debugging and modifications if needed,
        (E) The INA219 low-Ampere sensors,
        (F) A nRF24L01\protect\stepcounter{footnote}\protect\footnotemark[\value{footnote}] module used for wireless data transmissions.
    }
    \label{fig:truggysense_v2_logic_prototype}
\end{figure}
\addtocounter{footnote}{-1}
\footnotetext{The original 3.3V DC-DC step-down converter was unidentifiable and was thus replaced. Note that this module will be replaced by an AMS1117-3.3 for a more stable supply.}
\stepcounter{footnote}
\footnotetext{nRF24L01 is a 2.4GHz chip that uses its own proprietary protocol. The original module, an E01-ML01DP5, made use of this chip. It was replaced since it was unavailable.}
\begin{figure}[!t]
	\centering
	% https://imageonline.io/add-arrow/
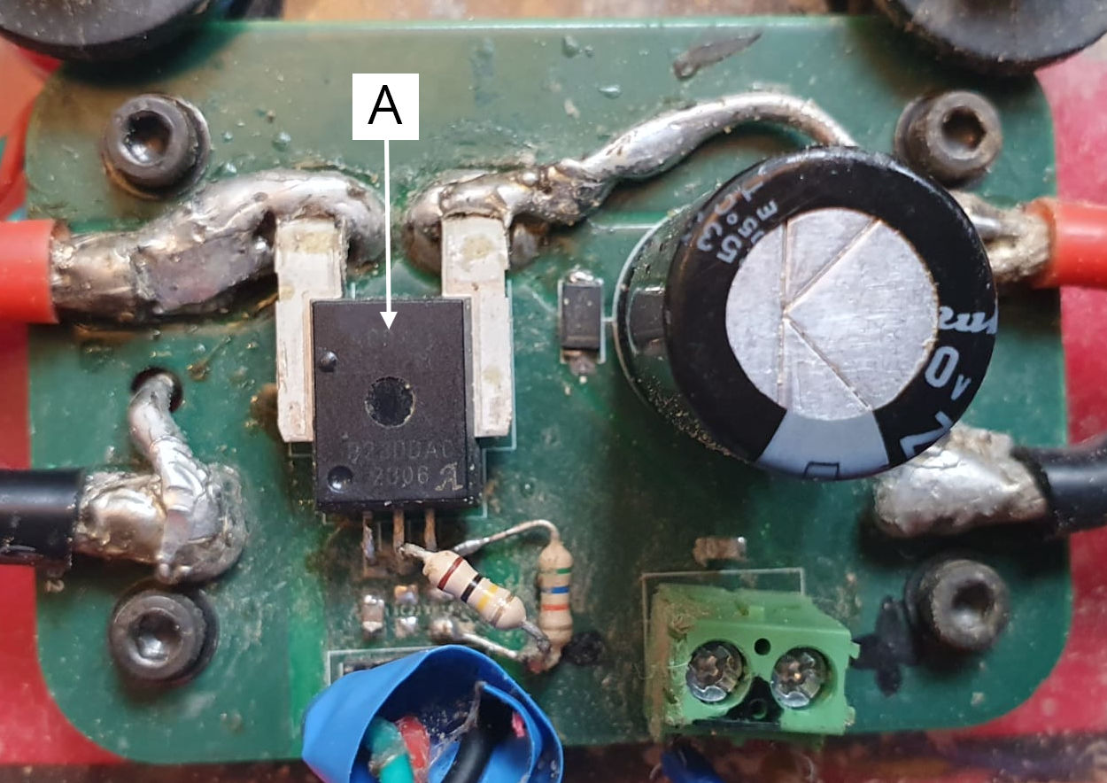
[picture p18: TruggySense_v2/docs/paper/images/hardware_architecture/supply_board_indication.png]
	
	\caption{
		The prototype supply board, with:
		(A) ACS756 high ampere sensor.
	}
	\label{fig:truggysense_v2_supply_prototype}
\end{figure}
\begin{figure}[!t]
	\centering
	% https://imageonline.io/add-arrow/
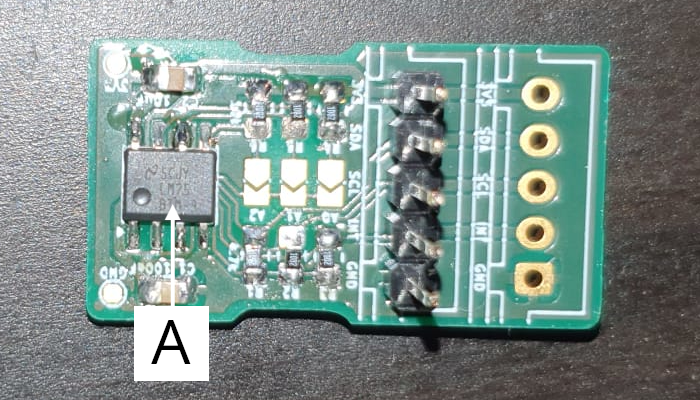
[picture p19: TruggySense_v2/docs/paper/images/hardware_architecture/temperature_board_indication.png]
	
	\caption{
		The prototype temperature board, with:
		(A) LM75 temperature sensor.
	}
	\label{fig:truggysense_v2_temperature_prototype}
\end{figure}

\subsection{Board design}
\ParagraphSeperator
The prototype makes use of a four-layer topology:

\noindent\centerline{Signal | GND | Vcc | Signal}

\noindent The final PCBs make use of a six-layer topology\footnote{The design of the final PCB was completed (as shown in Fig.~\ref{fig:board_logic}). However, it was not manufactured or tested due to time constraints. All experiments were therefore conducted using the prototype.}: 

\noindent\centerline{Signal | GND | 3V3 | 5V | GND | Signal}

\noindent Using this method, every component has a ground reference in close proximity.
Furthermore, both source planes have an adjacent ground plane, forming a distributed capacitor, as the FR4 layer acts as a dielectric, filtering high-frequency noise.

\ParagraphSeperator
For the design rules, certain standard values are applied to the signal lines, low power lines, and high power lines (as displayed in Tab.~\ref{tab:pcb_design_rules}).
The trace widths $W$ are determined using equation~\ref{eq:track_width}~~\cite{Daems2023,IPC1998}.
\begin{align}
    \label{eq:track_current}
    I & = k \cdot \Delta T^{0.44} \cdot (W \cdot H)^{0.725} \\
    W & = \frac{1}{H} \cdot \left(\frac{I}{k \cdot \Delta T^{0.44}}\right)^{1/0.725}
\end{align}

Seeing as, the middle layers of the PCB stack are reserved for either supply or ground planes, the traces will be part of the outside layers, resulting in k = 0.048.
As for the temperature rise $\Delta T$ and track thickness $t$ (or $H$), the standard values of 10°C and 0.035mm or 1.378 mil (1oz. copper) are used, respectively.
\begin{align}
    \label{eq:track_width}
    W & = \frac{1}{1.378} \cdot \left(\frac{I}{0.048 \cdot 10^{0.44}}\right)^{\frac{1}{0.725}} \\
	  & = \frac{1}{1.378} \cdot \left(\frac{I}{0.1322}\right)^{1.379}
\end{align}

This also means that a track width of $\sim$0.45m would be needed to allow a current of 200A.
Thus, a solid copper wire, with a core surface of 2.5mm², was added to support the high current provided by the battery.

\ParagraphSeperator
As for the vias, these should be as small as possible, while having enough surface to support the current that will pass through them.
This is determined using equation~\ref{eq:via_current}\footnote{The intermediate steps of these equations are found in the appendix under equation~\ref{eq:proof_track_width} and equation~\ref{eq:proof_via_width}.}.
\begin{align}
    \label{eq:via_surface}
    A & = A_{hole} - A_{hole - copper} \\
	  & = \pi \cdot t \cdot (d_{hole} - t)
\end{align}

\noindent Substituting it into equation~\ref{eq:track_current}, results in:
\begin{align}
    d_{hole} & = t + \frac{1}{\pi \cdot t} \cdot \left(\frac{I}{k \cdot \Delta T^{0.44}}\right)^{\frac{1}{0.725}} \\
	\label{eq:via_current}
             & = 1.378 + 0.231 \cdot \left(\frac{I}{0.1322}\right)^{1.3793}
\end{align}

\noindent The pad diameter is set to twice the hole diameter, to ensure a good connection between the via and the layers.

\ParagraphSeperator
Finally, for spacing, a 0.13mm clearance should suffice for the signal and low power lines~\cite{Daems2023}.
As for the high power lines, a clearance of at least 1mm is implemented to ensure that the ground plane of the logic and supply boards can never connect to each other.

\begin{table*}[!t]
	\centering
	\caption{PCB Design Rules}
	\begin{tabular}{lcccccccc}
		\toprule
			Line type & \multicolumn{2}{c}{Power}   						& \multicolumn{2}{c}{Traces} 					     & \multicolumn{3}{c}{Vias}   						                             & Spacing \\
					  &	\scriptsize{Voltage (V)} & \scriptsize{Current (A)} & \scriptsize{Width (mil)} & \scriptsize{Width (mm)} & \scriptsize{Hole (mil)}  & \scriptsize{Hole (mm)} & \scriptsize{Diameter (mm)} & \scriptsize{Clearance (mm)} \\
		\cmidrule(lr){2-3}\cmidrule(lr){4-5}\cmidrule(lr){6-8}\cmidrule(lr){9-9}
			Signal     & \textless 5.1  & \textless 0.1 & 0.494 & 0.0125 & 1.535 & 0.039 & 0.078 & 0.13 \\
			Low power  & \textless 5.1  & \textless 2   & 30.76 & 0.7814 & 11.17 & 0.284 & 0.568 & 0.26 \\
			High power & \textless 16.8 & \textless 200 & 17647 & 448.22 & 5619  & 142.7 & 285.4 & 1.3  \\
		\bottomrule
	\end{tabular}
	\label{tab:pcb_design_rules}
\end{table*}

\subsection{IWD support}
\ParagraphSeperator
One of the goals of the TruggySense second version (TruggySense V2) is to support IWD.
For this purpose, research towards custom-made motors has not been started, but is still ongoing.
Thus, support for both the old Corally Kagama system --containing the Corally Kuron 825 motor and Corally Torox 185 ESC--, and the new four motor system has to be included (Fig.~\ref{fig:truggysense_v2_above_base_plate_assembly}.J).

\ParagraphSeperator
The project towards these custom motors is currently developing direct drive motors\footnote{Direct drive motors are motors that are inserted into the socket of each wheel, eliminating the need for a gearbox.}.
This leads to the possibility of the current wheel encoders and motor temperature sensors becoming redundant, and a need for them to be integrated into the motor itself.
Compatibility for these new sensors is provided by the open pin headers (Fig.~\ref{fig:truggysense_v2_above_base_plate_assembly}.K), which are connected directly to pins of the LLC.

\subsection{Temperature sensor}
\ParagraphSeperator
When the system is operating, certain components can draw up to 200A under load, which may cause overheating and the failure of the component.
A Li-Po Battery must provide these peak currents, possibly overheating itself.
Therefore, monitoring these components is critical.

\ParagraphSeperator
Previously, this was done via DS18B20+, but this module is replaced by the LM75, due to its lower cost.
However, this comes with two drawbacks: fewer devices on the same bus, and reduced accuracy, going from ±0.5°C to ±2°C, though this should not affect the performance of the TruggySense V2.
The LM75 makes use of the I2C protocol, with each sensor having its own identifier, called an address.
These addresses are assigned by connecting the three address pins to either ground or its supply, leaving the module with eight usable addresses, compared to the 64-bit identifier of the DS18B20+.
Though, by adding an expansion module such as the LTC4316, the number of unique addresses for the LM75 can be increased to 32.

\subsection{Motion sensor}
\ParagraphSeperator
Whilst driving, some of the most critical metrics are the direction, acceleration, and velocity of the vehicle.
Currently, this is sensed and computed by a BNO085, a nine-degree-of-freedom (9-DoF) Inertial Measurement Unit (IMU).
Though a replacement was planned, being the PIM448 module, which integrates the ICM20498 chip with an integrated AK09916 magnetometer.
Unlike the BNO048, the PIM448 could not independently compute roll, pitch, and yaw; it could only provide raw rotational acceleration and magnetic field data.
To generate the orientation angles, a Mahony filter was implemented on the LLC, providing similar readings to the BNO085.
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

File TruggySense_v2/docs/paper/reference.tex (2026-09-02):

\documentclass[conference,a4paper]{IEEEtran}
\IEEEoverridecommandlockouts

% Some very useful LaTeX packages include:
% (uncomment the ones you want to load)
\usepackage[utf8]{inputenc}

% *** CITATION PACKAGES ***
%
\usepackage{cite}

% *** GRAPHICS RELATED PACKAGES ***
%
\usepackage[pdftex]{graphicx}
% declare the path(s) where your graphic files are
\graphicspath{{./Images/}}
% and their extensions so you won't have to specify these with
% every instance of \includegraphics
% \DeclareGraphicsExtensions{.PDF,.jpeg,.png}
\makeatletter
\newcommand\footnoteref[1]{\protected@xdef\@thefnmark{\ref{#1}}\@footnotemark}
\makeatother
% https://tex.stackexchange.com/a/35044

% *** MATH PACKAGES ***
%
\usepackage[cmex10]{amsmath}
\usepackage[detect-all]{siunitx}

% *** SPECIALIZED LIST PACKAGES ***
%
\usepackage{algorithmic}

% *** ALIGNMENT PACKAGES ***
%
%\usepackage{array}

%\usepackage{mdwmath}
%\usepackage{mdwtab}

% IEEEtran contains the IEEEeqnarray family of commands that can be used to
% generate multiline equations as well as matrices, tables, etc., of high
% quality.

%\usepackage{eqparbox}

% *** SUBFIGURE PACKAGES ***
%\usepackage[tight,footnotesize]{subfigure}
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

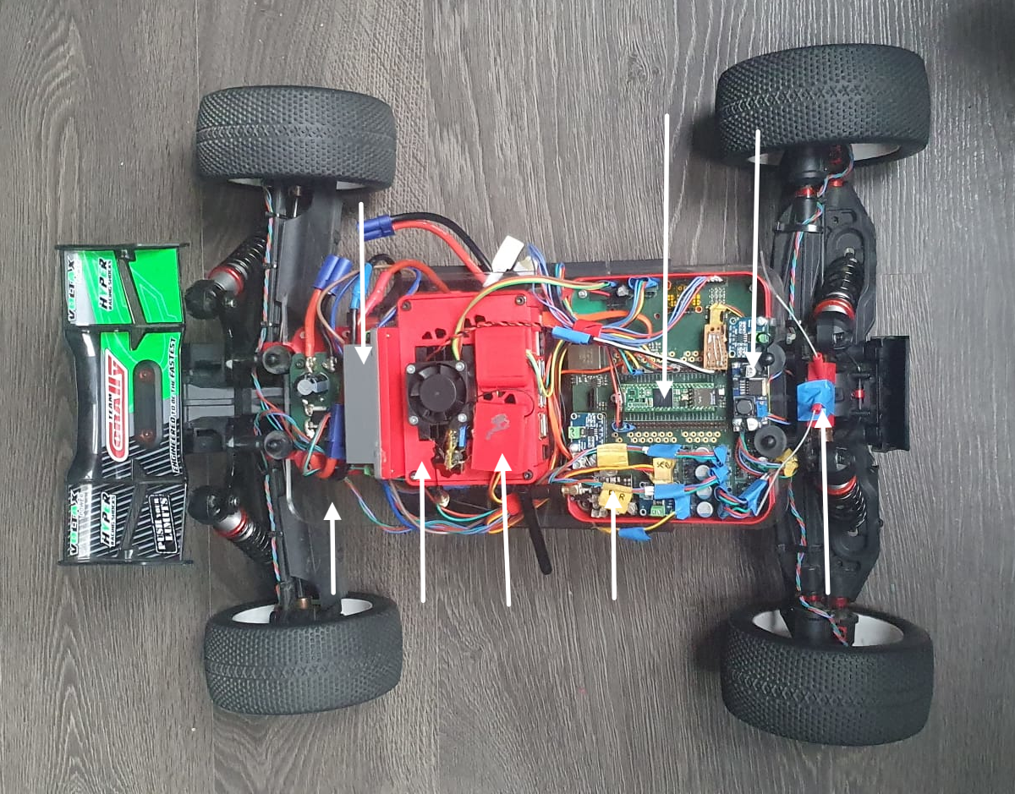
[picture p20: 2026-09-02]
TruggySense_v2/docs/paper/images/hardware_architecture/car_middle_arrows_1.png

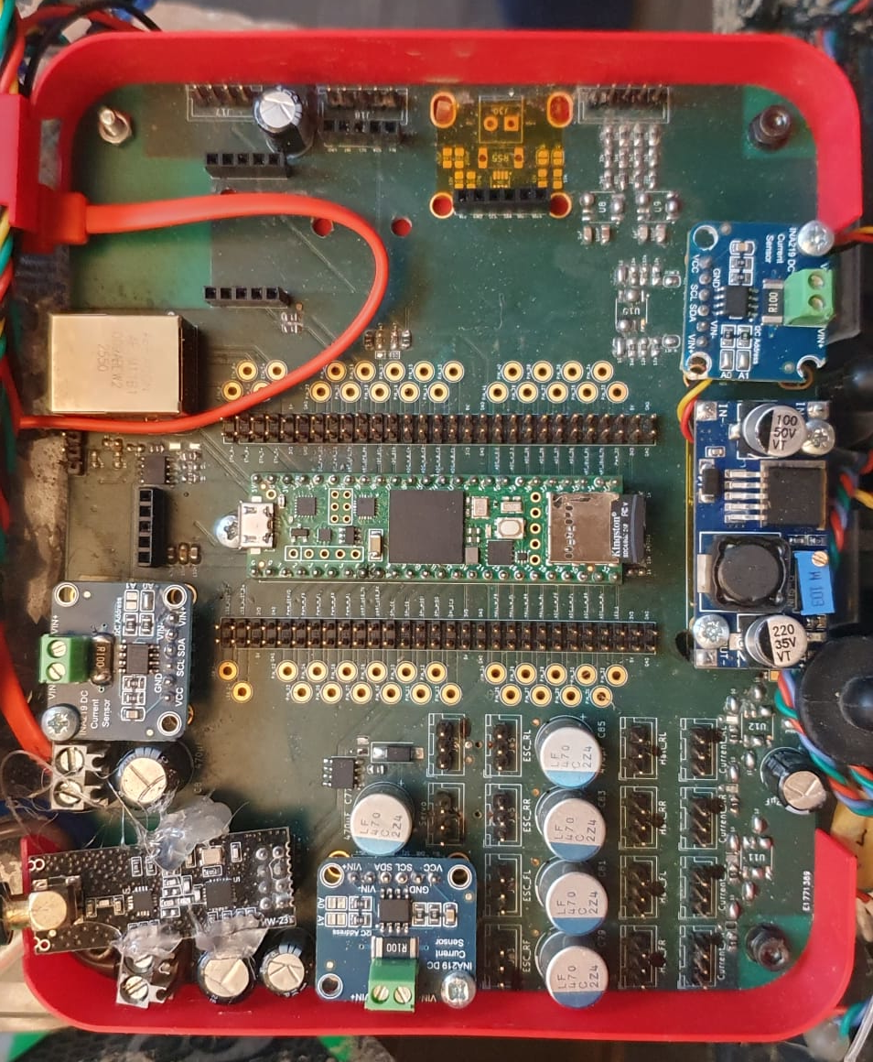
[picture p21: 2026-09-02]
TruggySense_v2/docs/paper/images/hardware_architecture/logic_board.png

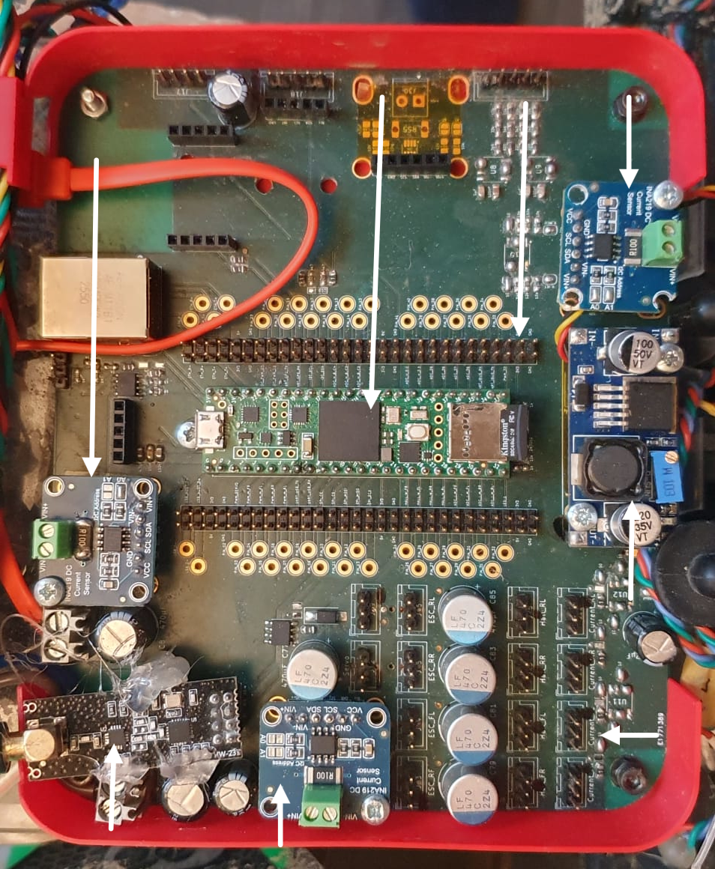
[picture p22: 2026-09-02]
TruggySense_v2/docs/paper/images/hardware_architecture/logic_board_arrow.png

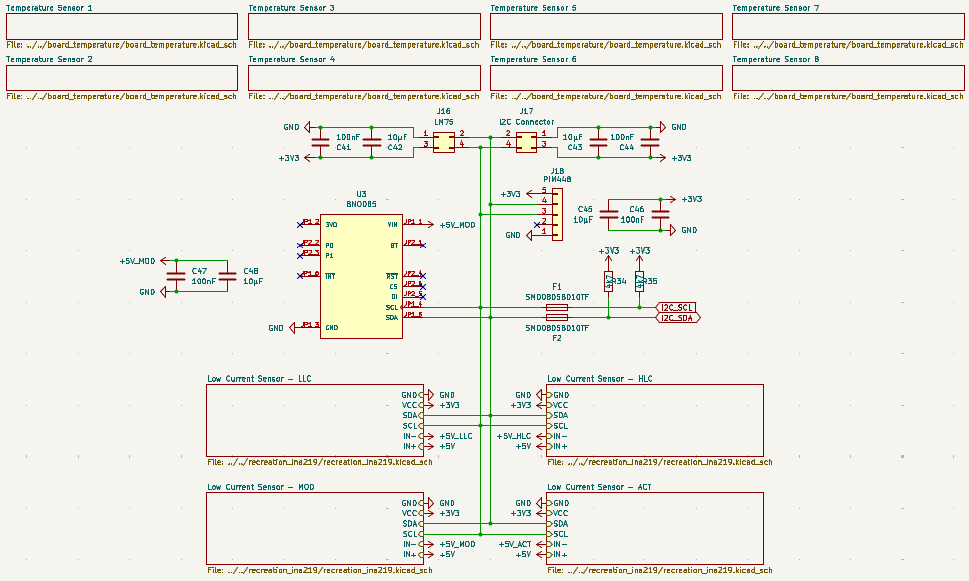
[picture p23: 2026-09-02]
TruggySense_v2/docs/portfolio/images/design/kicad/schematic/v3/logic_i2c.png

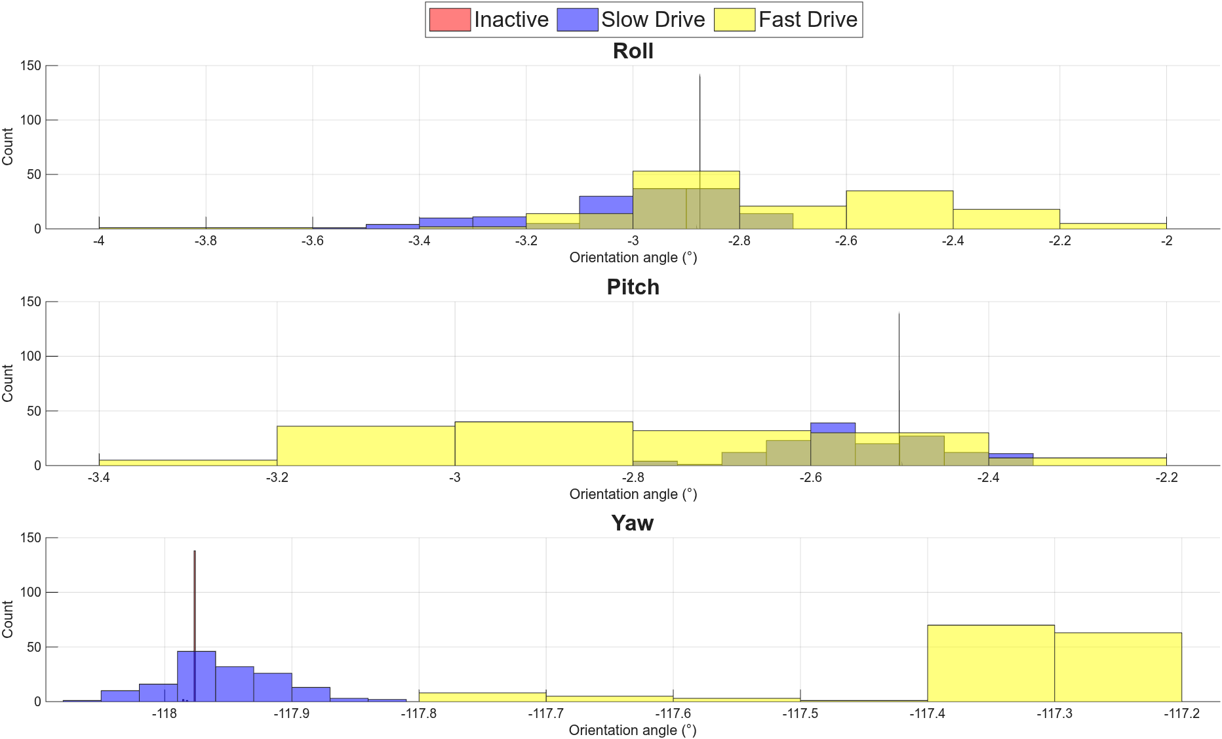
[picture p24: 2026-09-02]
TruggySense_v2/docs/paper/images/stationary/exp_IMU.png

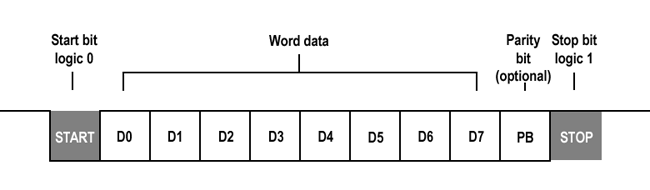
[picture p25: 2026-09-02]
TruggySense_v2/docs/portfolio/images/explenations/uart_signal.png

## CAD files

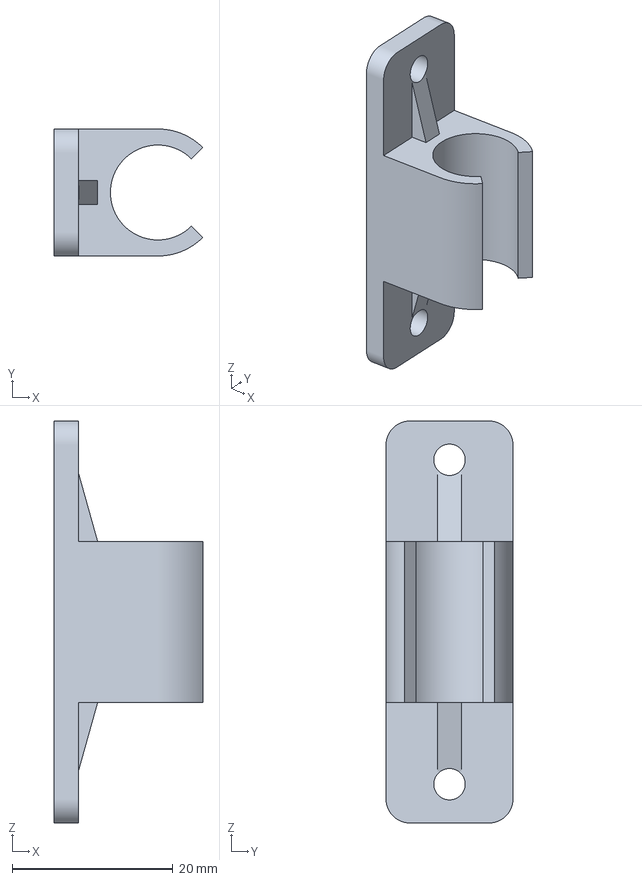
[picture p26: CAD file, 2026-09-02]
TruggySense_v2/cad/FreeCad/generated_files/3mf/front_tube_clamp.3mf
18.5 x 15.8 x 50.0 mm

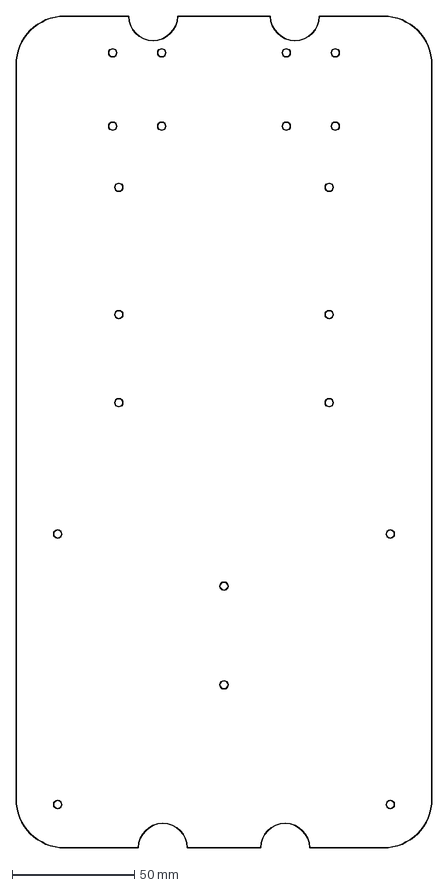
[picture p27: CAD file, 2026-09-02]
TruggySense_v2/cad/FreeCad/generated_files/dxf/base_plate.dxf
170.0 x 340.0 mm

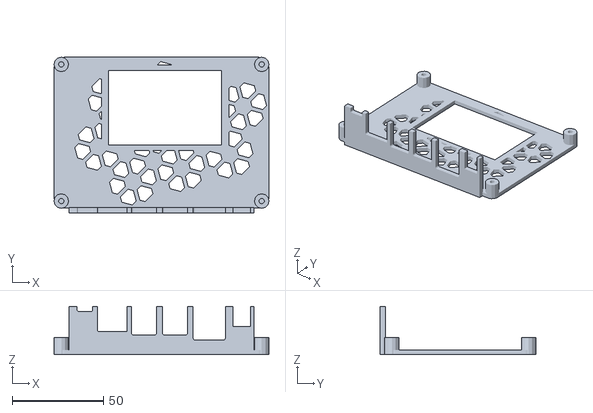
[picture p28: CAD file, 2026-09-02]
TruggySense_v2/cad/FreeCad/generated_files/stl/Jetson_Case/jetson_case_cover.stl
118.0 x 85.5 x 26.6

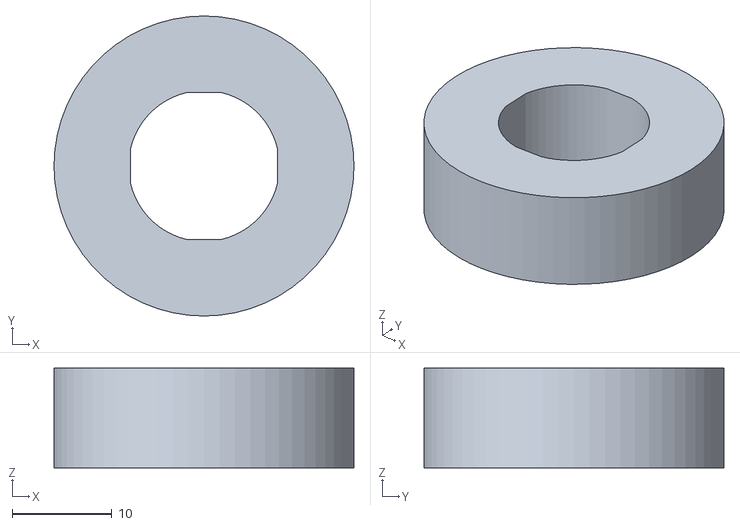
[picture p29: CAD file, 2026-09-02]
TruggySense_v2/cad/FreeCad/generated_files/stl/wheel_holder.stl
30.0 x 30.0 x 10.0

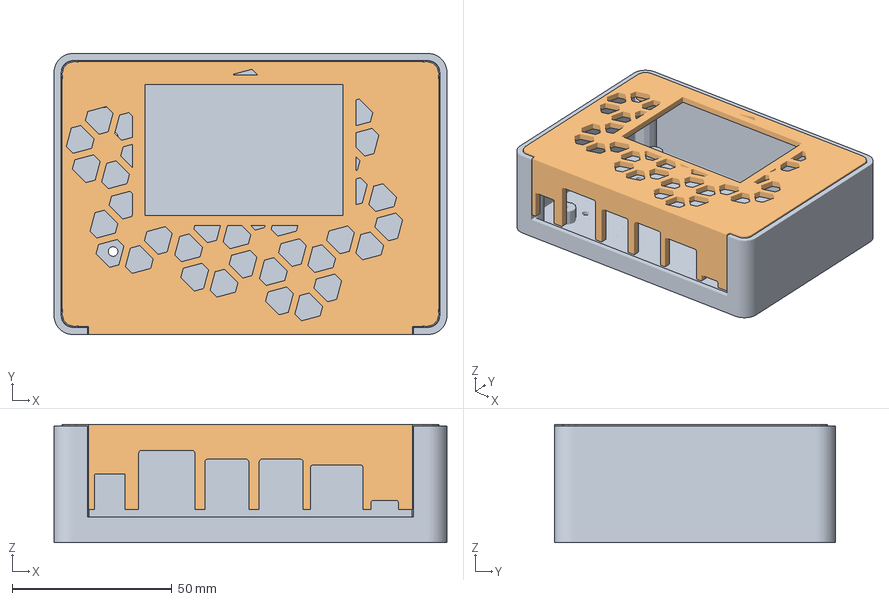
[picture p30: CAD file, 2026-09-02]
TruggySense_v2/cad/FreeCad/v3/jetson_case.FCStd
123.0 x 88.0 x 37.0 mm
jeston_case_bottom_edit
jetson_case_cover

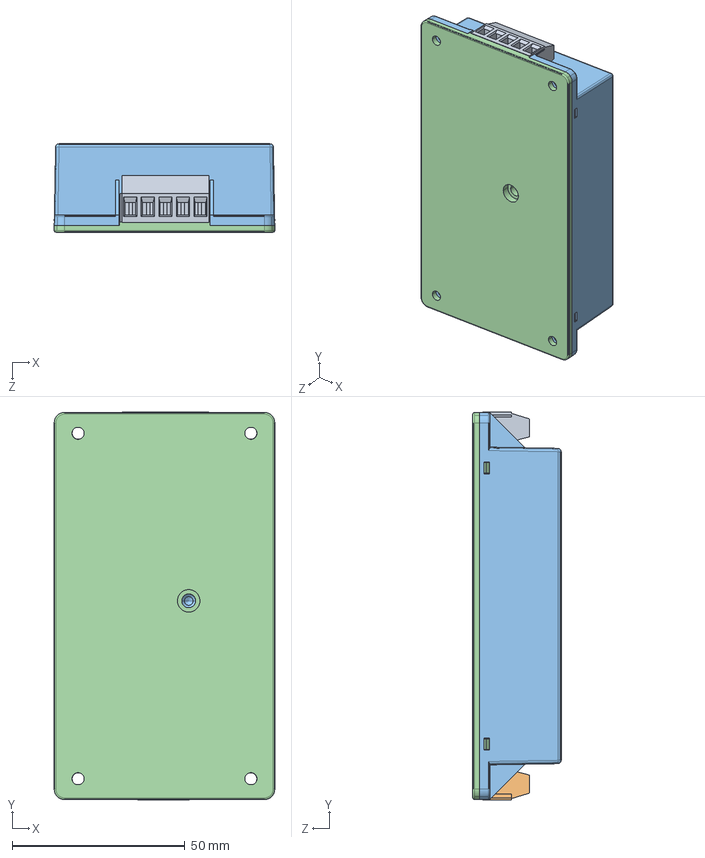
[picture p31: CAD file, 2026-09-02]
TruggySense_v2/cad/FreeCad/v3/stl/tmdc40_tmdc40h_3d_drawing.stp
63.8 x 112.2 x 25.6 mm

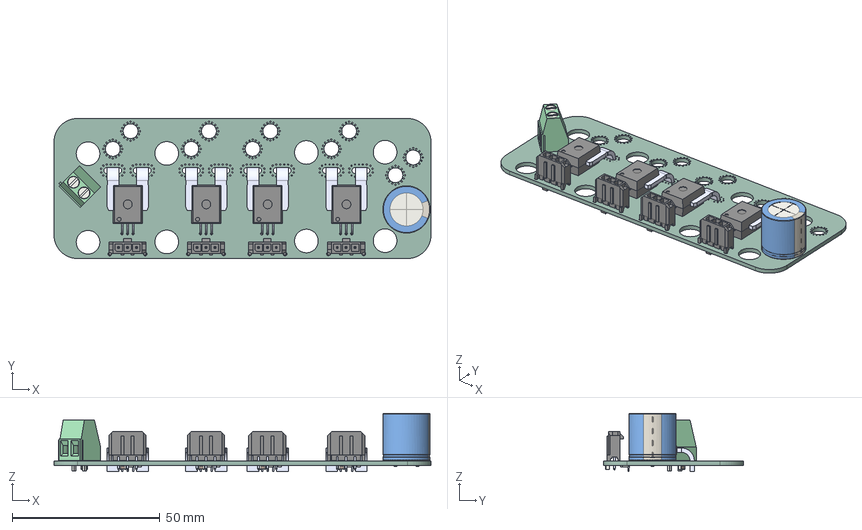
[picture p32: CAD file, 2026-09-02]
TruggySense_v2/cad/KiCAD/v3/board_supply/2_power_board.step
127.8 x 47.5 x 19.7 mm
TerminalBlock_Phoenix_MKDS-1,5-2-5.08_1x02_P5.08mm_Horizontal
ACS773LCB-050B-PFF-T x 4
CP_Radial_D16.0mm_P7.50mm
R_0805_2012Metric x 8
C_0805_2012Metric x 5
board_supply_PCB

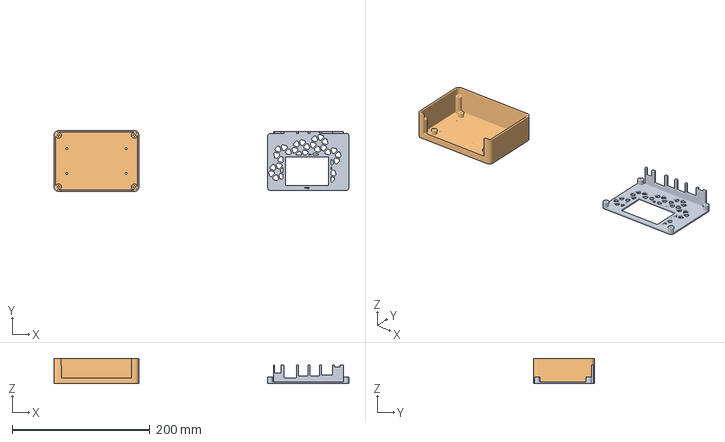
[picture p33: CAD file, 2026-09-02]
TruggySense_v2/cad/FreeCad/generated_files/3mf/jetson_case.3mf
427.7 x 88.0 x 36.5 mm

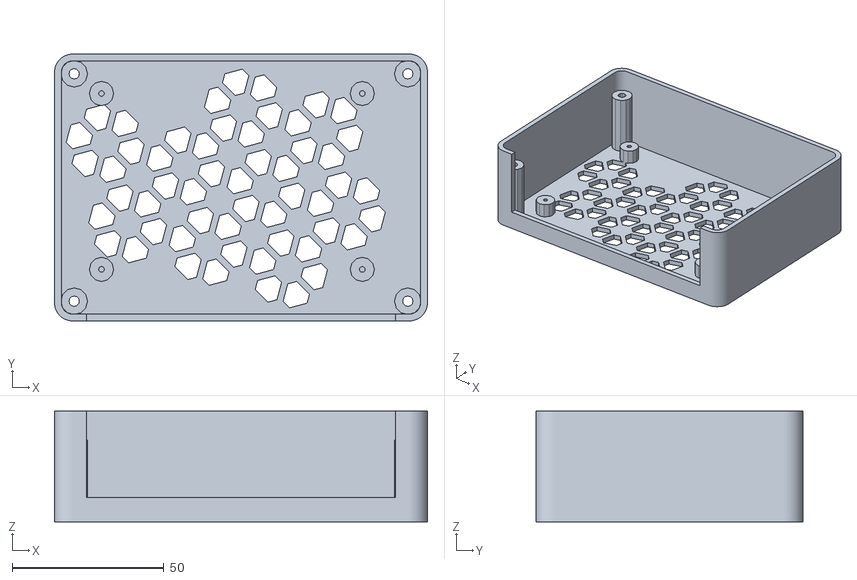
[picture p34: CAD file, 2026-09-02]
TruggySense_v2/cad/FreeCad/generated_files/stl/Jetson_Case/jetson_case.stl
123.0 x 88.0 x 36.5

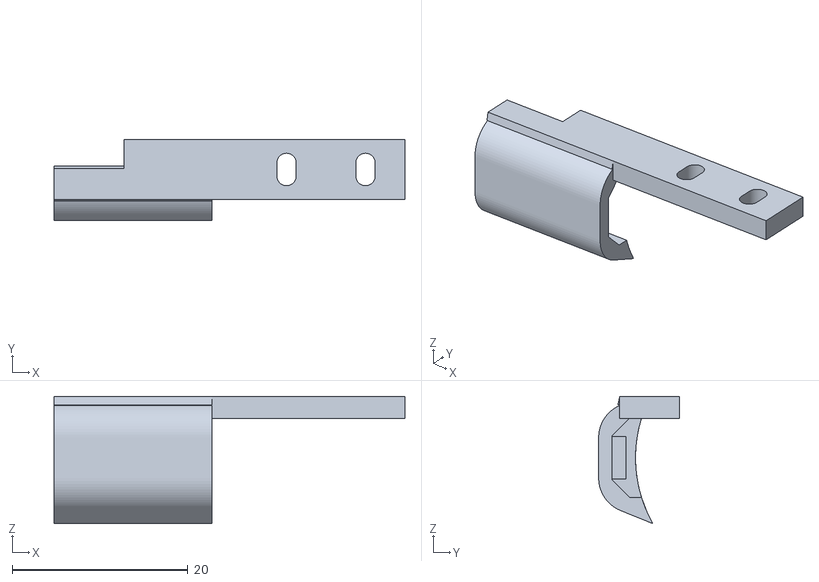
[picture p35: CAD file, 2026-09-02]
TruggySense_v2/cad/FreeCad/generated_files/stl/Wheel_encoder-rear_encoderBody004.stl
40.0 x 9.20 x 14.5

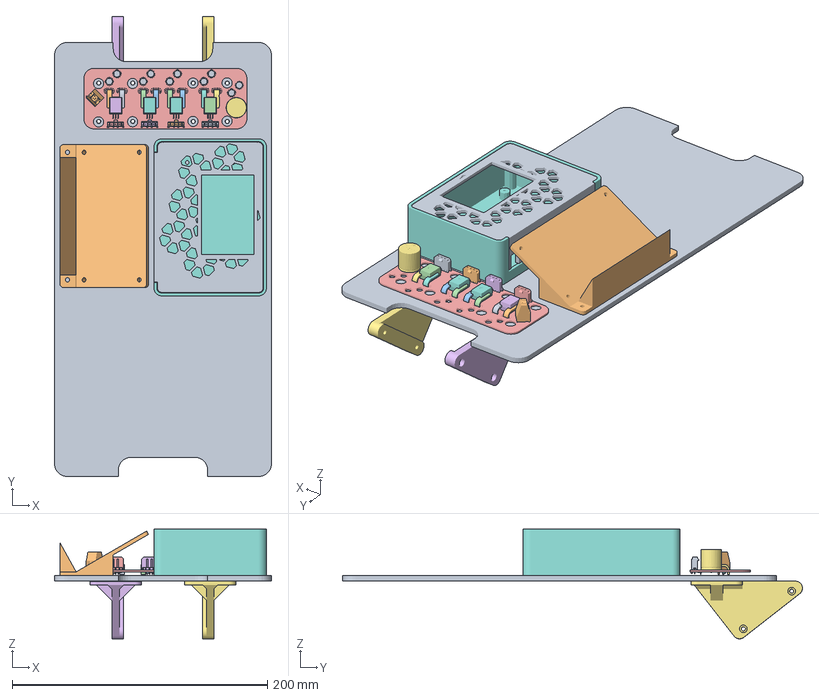
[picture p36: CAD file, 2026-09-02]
TruggySense_v2/cad/FreeCad/v3/base.FCStd
170.0 x 360.3 x 86.0 mm
TerminalBlock_Phoenix_MKDS-1,5-2-5.08_1x02_P5.08mm_Horizontal
ACS773LCB-050B-PFF-T
ACS773LCB-050B-PFF-T001
ACS773LCB-050B-PFF-T002
ACS773LCB-050B-PFF-T003
ACS773LCB-050B-PFF-T004
ACS773LCB-050B-PFF-T005
ACS773LCB-050B-PFF-T007
ACS773LCB-050B-PFF-T008
ACS773LCB-050B-PFF-T009
ACS773LCB-050B-PFF-T010
ACS773LCB-050B-PFF-T011
ACS773LCB-050B-PFF-T012
CP_Radial_D16.0mm_P7.50mm
ACS773LCB-050B-PFF-T014
ACS773LCB-050B-PFF-T015
ACS773LCB-050B-PFF-T016
ACS773LCB-050B-PFF-T017
ACS773LCB-050B-PFF-T018
ACS773LCB-050B-PFF-T019
ACS773LCB-050B-PFF-T021
ACS773LCB-050B-PFF-T022
ACS773LCB-050B-PFF-T023
ACS773LCB-050B-PFF-T024
ACS773LCB-050B-PFF-T025
ACS773LCB-050B-PFF-T026
R_0805_2012Metric
R_0805_2012Metric001
C_0805_2012Metric
R_0805_2012Metric002
R_0805_2012Metric003
C_0805_2012Metric001
C_0805_2012Metric002
R_0805_2012Metric004
C_0805_2012Metric003
R_0805_2012Metric005
R_0805_2012Metric006
C_0805_2012Metric004
R_0805_2012Metric007
board_supply_PCB
rear_mount_left
rear_mount_right
jetson_case
jetson_cover
tmdc_holder

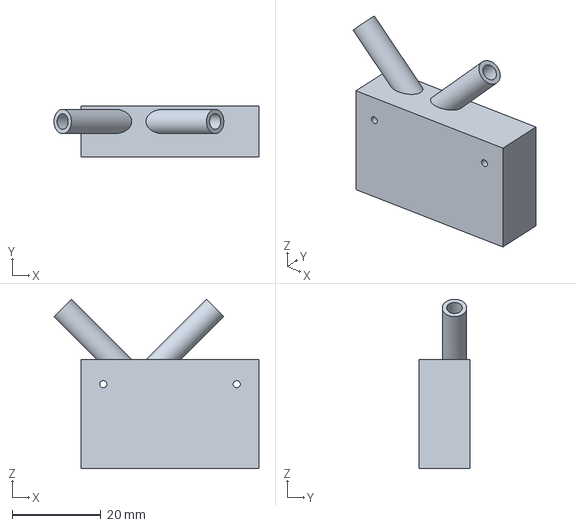
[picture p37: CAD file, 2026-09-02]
TruggySense_v2/cad/FreeCad/generated_files/3mf/x6b_case.3mf
46.1 x 11.5 x 38.1 mm

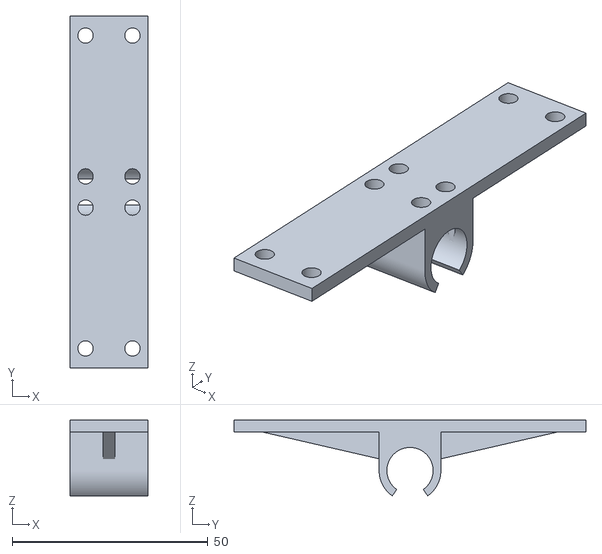
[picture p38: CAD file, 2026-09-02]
TruggySense_v2/cad/FreeCad/generated_files/stl/RC_1-8_custom_mount-tube_clamp_front.stl
20.0 x 90.0 x 19.4

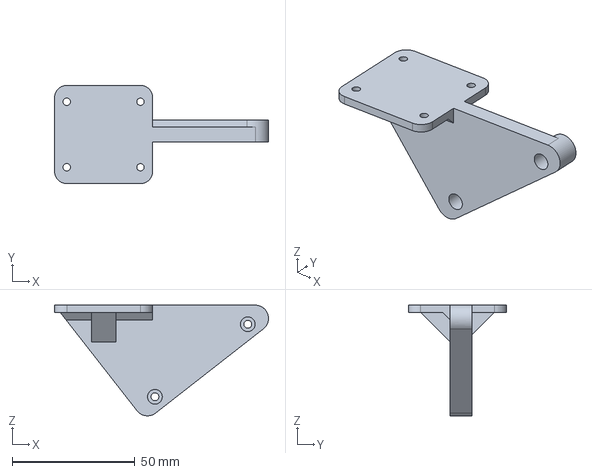
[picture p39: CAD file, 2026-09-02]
TruggySense_v2/cad/FreeCad/v3/rear_mount.FCStd
87.2 x 40.0 x 45.1 mm

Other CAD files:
TruggySense_v2/cad/FreeCad/v3/3mf/jetson_cover.3mf
TruggySense_v2/cad/FreeCad/generated_files/3mf/rear_mount.3mf
TruggySense_v2/cad/FreeCad/generated_files/stl/Wheel_encoder-front_encoderBody003.stl
TruggySense_v2/cad/FreeCad/v3/tmdc_holder.FCStd
TruggySense_v1/cad/OpenSCAD/Circuit_plate_holder_imu.scad
TruggySense_v1/cad/OpenSCAD/base_holder.scad
TruggySense_v1/cad/OpenSCAD/Circuit_plate_holder.scad
TruggySense_v1/cad/OpenSCAD/Circuit_plate_holder_base_station.scad
TruggySense_v1/cad/FreeCAD/DXF/base_plate-BodySketch.dxf
TruggySense_v1/cad/FreeCAD/RC_1-10_Truggy_Platform.FCStd
TruggySense_v1/cad/FreeCAD/RC_1-8_Kagama_custom_mount.FCStd
TruggySense_v1/cad/FreeCAD/STL/AH3323A-P-B.stp
TruggySense_v1/cad/FreeCAD/STL/RC_1-8_Kagama_custom_mount-Plate_carrierread_mount_V2 (Mirror #1).stl
TruggySense_v1/cad/FreeCAD/STL/RC_1-8_custom_mount-Cable_Management.3mf
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

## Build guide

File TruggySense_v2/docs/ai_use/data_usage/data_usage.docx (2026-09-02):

I-MAP: Logbook (AI Usage)

TSMK

Universiteit van Antwerpen

Toegepaste Ingenieurswetenschappen (Elektronica-ICT)

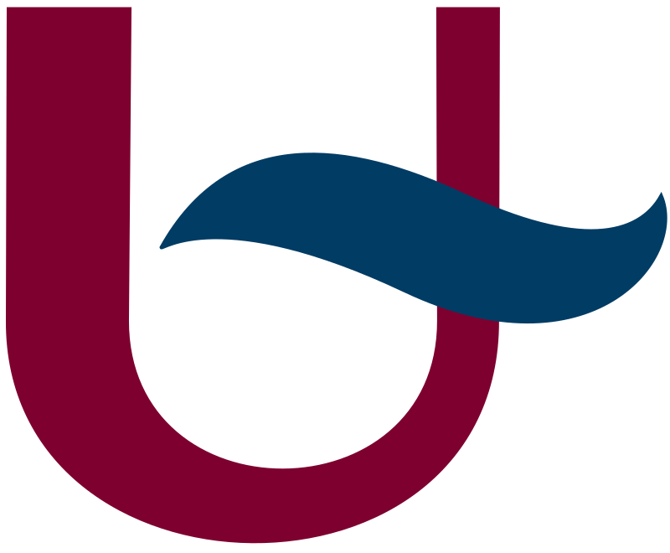
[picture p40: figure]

# LLM request

- Claude (https://claude.ai) was used for this prompt.

Is it possible to get something like this when flashing my platform.IO project?
RAM: [= ] 8.3% (used 27196 bytes from 327680 bytes)
Flash: [== ] 16.2% (used 267988 bytes from 1655808 bytes)

# LLM resopnse

Yes! Add this to your platformio.ini:

ini

[env:teensy41]

platform = teensy

board = teensy41

framework = arduino

check_tool = clangtidy

extra_scripts = pre:print_size.py

Actually, the simpler fix is just a custom_size_format option — but unfortunately Teensy's platform doesn't support that directly.

The most reliable way is a small extra script. Create a file called print_size.py in your project root:

python

Import("env")

import subprocess

import os

def print_size(source, target, env):

elf = str(target[0])

size_tool = os.path.join(

env.subst("$PROJECT_PACKAGES_DIR"),

"toolchain-gccarmnoneeabi-teensy", "bin", "arm-none-eabi-size"

)

result = subprocess.run([size_tool, elf], capture_output=True, text=True)

lines = result.stdout.strip().split("\n")

if len(lines) >= 2:

parts = lines[1].split()

text, data, bss = int(parts[0]), int(parts[1]), int(parts[2])

flash_used = text + data

ram_used = data + bss

flash_total = 7 * 1024 * 1024 + 750 * 1024 # 7.75MB

ram_total = 512 * 1024

def bar(used, total, width=10):

filled = int(round(used / total * width))

return "[" + "=" * filled + " " * (width - filled) + "]"

print(f"RAM: {bar(ram_used, ram_total)} {ram_used/ram_total*100:.1f}% (used {ram_used} bytes from {ram_total} bytes)")

print(f"Flash: {bar(flash_used, flash_total)} {flash_used/flash_total*100:.1f}% (used {flash_used} bytes from {flash_total} bytes)")

env.AddPostAction("$BUILD_DIR/${PROGNAME}.elf", print_size)

Then in your platformio.ini, just add the extra script line:

ini

[env:teensy41]

platform = teensy

board = teensy41

framework = arduino

extra_scripts = post:print_size.py

Now every pio run or pio run -t upload will print:

RAM: [= ] 8.3% (used 43520 bytes from 524288 bytes)

Flash: [== ] 16.2% (used 267988 bytes from 8114176 bytes)

The script hooks into the post-build step so it runs automatically after linking, before uploading.

I-MAP: Logbook (AI Usage) TSMK

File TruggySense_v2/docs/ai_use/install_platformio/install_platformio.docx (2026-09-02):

I-MAP: Logbook (AI Usage)

TSMK

Universiteit van Antwerpen

Toegepaste Ingenieurswetenschappen (Elektronica-ICT)


# LLM request

- ChatGPT (https://chatgpt.com)was used for this prompt.

install platform.io

# LLM resopnse

To install PlatformIO, the recommended way is through Visual Studio Code as an extension.

✅ Option 1 (Recommended): Install PlatformIO in VS Code

1️⃣ Install Visual Studio Code

Download and install from:
https://code.visualstudio.com/

2️⃣ Install PlatformIO Extension

1. Open Visual Studio Code
2. Click the Extensions icon (left sidebar)
3. Search for PlatformIO IDE
4. Click Install

The extension will automatically install:

- PlatformIO Core
- Python (if needed)
- Required toolchains

✅ Option 2: Install PlatformIO Core (CLI only)

If you prefer command line:

🔹 Windows (PowerShell)

pip install -U platformio

🔹 macOS / Linux

pip3 install -U platformio

After installation, verify:

pio --version

⚡ If pip is not installed

Install Python first from:
https://python.org

Then ensure pip works:

python -m ensurepip --upgrade

🔥 Alternative: Install via Homebrew (macOS)

If you use Homebrew:

brew install platformio

If you tell me:

- Your OS (Windows / macOS / Linux)
- Whether you want GUI (VS Code) or CLI only

I can give you step-by-step instructions tailored to your setup.

# LLM request

I'm using debian 12 and have installed it via vs-code plugins. When i try "pio boards" in the command prompt it sais "bash: pio: command not found".

# LLM resopnse

This is expected behavior 👍 — when you install PlatformIO via Visual Studio Code, the pio command is not automatically added to your system PATH.

The extension uses its own internal PlatformIO Core.

✅ Solution Options (Debian 12)

🔹 Option 1 (Easiest): Use PlatformIO inside VS Code

Instead of pio boards, use:

1. Open VS Code
2. Open Command Palette (Ctrl + Shift + P)
3. Type:
4. PlatformIO: Boards

Or open the PlatformIO Home tab → Boards.

No terminal needed.

🔹 Option 2: Use PlatformIO Core from VS Code’s internal location

PlatformIO installed by the extension usually lives here:

~/.platformio/penv/bin/pio

Try:

~/.platformio/penv/bin/pio boards

If that works, then your issue is just PATH.

🔹 Option 3 (Recommended if you want CLI access): Add it to PATH

Edit your .bashrc:

nano ~/.bashrc

Add this line at the bottom:

export PATH="$HOME/.platformio/penv/bin:$PATH"

Save and reload:

source ~/.bashrc

Now test:

pio --version
pio boards

🔹 Option 4 (Cleanest CLI setup): Install PlatformIO Core globally

If you want full CLI independence from VS Code:

pip3 install -U platformio

Then:

pio --version

🧠 Why This Happens

The VS Code extension installs:

- PlatformIO Core
- A private Python virtual environment

It does not modify your system shell configuration (which is actually good practice).

If you want, tell me:

- Do you want to use PlatformIO mainly inside VS Code?
- Or do you plan to automate builds via terminal/CI?

I can recommend the best long-term setup for Debian.

# LLM request

How can i check all connected boards

# LLM resopnse

On Debian 12, there are two slightly different things you might mean by “connected boards”:

1. Boards physically connected via USB
2. Boards supported by PlatformIO

I’ll show both.

✅ 1️⃣ Check physically connected boards (USB devices)

🔹 List USB devices

lsusb

You should see something like:

Bus 001 Device 005: ID 2341:0043 Arduino SA Uno R3

If you’re using something like an ESP32, you may see:

- Silicon Labs CP210x
- CH340
- FTDI
- etc.

🔹 Check available serial ports

Most dev boards show up as a serial device:

ls /dev/ttyUSB*
ls /dev/ttyACM*

Or more reliably:

dmesg | grep tty

After plugging in the board.

✅ 2️⃣ Using PlatformIO to detect connected boards

Inside terminal (if pio works):

pio device list

This shows connected serial devices.

Or the more detailed command:

pio device monitor

✅ 3️⃣ Inside VS Code (if CLI isn’t configured)

In Visual Studio Code:

1. Open Command Palette (Ctrl + Shift + P)
2. Run:
3. PlatformIO: List Serial Ports

Or open:
PlatformIO Home → Devices

🚨 If Your Board Doesn’t Show Up

Common causes on Debian:

🔹 Missing permissions (very common)

Add yourself to the dialout group:

sudo usermod -a -G dialout $USER

Then log out and log back in.

🔹 Bad USB cable

Some USB cables are power-only (no data).

🔹 Driver issues

Most Arduino/ESP boards work out of the box on Debian 12, but if it’s a CH340-based board, you can check:

lsmod | grep ch34

🔎 If You Tell Me:

- Which board model?
- Does lsusb show anything?
- Does /dev/ttyUSB0 or /dev/ttyACM0 appear?

I can diagnose it step-by-step.

# LLM request

pio device list worked

How can i upload to that board

# LLM resopnse

Great 👍 since pio device list works, you’re ready to upload.

Uploading with PlatformIO requires a project (you can’t upload a random .ino file directly like in the Arduino IDE).

✅ Step 1 — Create a Project

Inside a working directory:

mkdir my_project
cd my_project
pio project init --board <board_id>

You need the correct <board_id>.

To find it:

pio boards

Example:

- Arduino Uno → uno
- ESP32 Dev Module → esp32dev
- ESP8266 NodeMCU → nodemcuv2

Example:

pio project init --board uno

✅ Step 2 — Add Your Code

Edit:

src/main.cpp

Example test:

#include <Arduino.h>

void setup() {
pinMode(LED_BUILTIN, OUTPUT);
}

void loop() {
digitalWrite(LED_BUILTIN, HIGH);
delay(500);
digitalWrite(LED_BUILTIN, LOW);
delay(500);
}

✅ Step 3 — Upload to the Board

Now simply run:

pio run --target upload

PlatformIO will:

1. Compile
2. Detect the serial port
3. Upload automatically

🔧 If Auto-detection Fails

Find your port:

pio device list

Example output:

/dev/ttyUSB0

Then upload with explicit port:

pio run --target upload --upload-port /dev/ttyUSB0

🔥 Optional: Add Upload Port Permanently

Edit platformio.ini:

upload_port = /dev/ttyUSB0

🧠 Quick Alternative (Inside VS Code)

If using Visual Studio Code:

Just click the Upload → arrow button in the bottom bar.

If you tell me your exact board model, I can give you the exact board ID and a working minimal config.

# LLM request

The teensy does blink but the upload states there is a problem

pio run -t upload --upload-port /dev/ttyACM0

Processing teensy41 (platform: teensy; board: teensy41; framework: arduino)

Verbose mode can be enabled via -v, --verbose option

CONFIGURATION: https://docs.platformio.org/page/boards/teensy/teensy41.html

PLATFORM: Teensy (5.0.0) > Teensy 4.1 HARDWARE: IMXRT1062 600MHz, 512KB RAM, 7.75MB Flash

DEBUG: Current (jlink) External (jlink)

PACKAGES:

- framework-arduinoteensy @ 1.159.0 (1.59)

- tool-teensy @ 1.159.0 (1.59)

- toolchain-gccarmnoneeabi-teensy @ 1.110301.0 (11.3.1)

LDF: Library Dependency Finder -> https://bit.ly/configure-pio-ldf

LDF Modes: Finder ~ chain, Compatibility ~ soft Found 92 compatible libraries

Scanning dependencies...

No dependencies

Building in release mode

Linking .pio/build/teensy41/firmware.elf

Checking size .pio/build/teensy41/firmware.elf

Advanced Memory Usage is available via "PlatformIO Home > Project Inspect"

Building .pio/build/teensy41/firmware.hex Configuring upload protocol...

AVAILABLE: jlink, teensy-cli, teensy-gui

CURRENT: upload_protocol = teensy-gui Uploading .pio/build/teensy41/firmware.hex

Opening Teensy Loader...

error sending reboot command to /dev/hidraw3

# LLM resopnse

Perfect — this error tells us exactly what’s wrong 👍

You’re using a Teensy 4.1, and Teensy boards do NOT upload over /dev/ttyACM0 like Arduino boards.

They upload via USB HID, not serial.

Your error:

error sending reboot command to /dev/hidraw3

means Linux permission issue on the HID device.

✅ ✅ FIX (Debian 12)

You must add proper udev rules for Teensy.

🔹 Step 1 — Create udev rule

sudo nano /etc/udev/rules.d/49-teensy.rules

Paste this:

SUBSYSTEM=="usb", ATTR{idVendor}=="16c0", MODE:="0666"
KERNEL=="hidraw*", ATTRS{idVendor}=="16c0", MODE:="0666"

Save and exit.

🔹 Step 2 — Reload udev

sudo udevadm control --reload-rules
sudo udevadm trigger

🔹 Step 3 — Unplug and replug the Teensy

Now try:

pio run -t upload

⚠️ Remove --upload-port. It is NOT needed for Teensy.

🔎 Why This Happens

Teensy uses:

- Vendor ID: 16c0
- HID device: /dev/hidrawX

Linux blocks access to /dev/hidraw* by default for normal users.

The rule fixes that.

🔥 Alternative (Quick Test)

You can confirm it’s a permission issue by trying:

sudo pio run -t upload

If that works → 100% udev permission problem.

But don’t use sudo permanently — fix the rule instead.

🧠 Also Important

In your log:

CURRENT: upload_protocol = teensy-gui

You can switch to CLI uploader (more reliable on Linux):

Edit platformio.ini:

upload_protocol = teensy-cli

Then upload again.

This avoids the graphical Teensy Loader.

🚀 After This

It should upload instantly without pressing the reset button.

If it still fails, send:

ls -l /dev/hidraw*

and I’ll diagnose it precisely.

erfect — this error tells us exactly what’s wrong 👍

I-MAP: Logbook (AI Usage) TSMK

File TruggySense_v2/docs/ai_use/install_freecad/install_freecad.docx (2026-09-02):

I-MAP: Logbook (AI Usage)

TSMK

Universiteit van Antwerpen

Toegepaste Ingenieurswetenschappen (Elektronica-ICT)


# LLM request

- ChatGPT (https://chatgpt.com)was used for this prompt.

How can i install FreeCad 1.0 on my debian 12 machine

# LLM resopnse

On Debian 12 (Bookworm) the repository version of FreeCAD is old (around 0.20). Debian stable usually doesn’t update major versions after release, so FreeCAD 1.0 isn’t in the official Debian 12 repos.

So you need one of these methods.

Option 1 (Best & simplest): AppImage

This is usually the easiest way to run FreeCAD 1.0 on Debian.

1. Download

Go to the official downloads and get the Linux AppImage:

- https://www.freecad.org/downloads.php

Example from terminal:

wget https://github.com/FreeCAD/FreeCAD/releases/download/1.0.0/FreeCAD_1.0.0-Linux-x86_64.AppImage

2. Make executable

chmod +x FreeCAD_1.0.0-Linux-x86_64.AppImage

3. Run it

./FreeCAD_1.0.0-Linux-x86_64.AppImage

✔ No installation needed
✔ Uses its own dependencies
✔ Safest for Debian stable

Option 2: Flatpak (very common)

If you use Flatpak:

Install flatpak

sudo apt install flatpak

Add Flathub

flatpak remote-add --if-not-exists flathub https://flathub.org/repo/flathub.flatpakrepo

Install FreeCAD

flatpak install flathub org.freecad.FreeCAD

Run with:

flatpak run org.freecad.FreeCAD

Option 3: Snap

If you use Snap packages:

sudo apt install snapd
sudo snap install freecad

Snaps bundle dependencies and update automatically.

Option 4 (not recommended): Debian unstable package

FreeCAD 1.0 exists in Debian unstable (sid) packages.
But installing it on Debian 12 can create a “FrankenDebian” due to dependency upgrades.

✅ Recommendation for Debian 12:
Use AppImage or Flatpak.

- AppImage → simplest
- Flatpak → integrates with desktop menus

💡 If you want, I can also show you a nice way to integrate the AppImage into your Debian menu (with icon + launcher) so it behaves like a normal installed app.

# LLM request

How can i integrate the appimage into the desktop menus

# LLM resopnse

To integrate the FreeCAD AppImage into your Debian 12 desktop menu, you just need to create a .desktop launcher and add an icon. This works on GNOME, KDE, XFCE, Cinnamon, etc. 🐧

1️⃣ Move the AppImage to a permanent location

Create a folder for AppImages and move it there:

mkdir -p ~/Applications
mv FreeCAD_1.0.0-Linux-x86_64.AppImage ~/Applications/
chmod +x ~/Applications/FreeCAD_1.0.0-Linux-x86_64.AppImage

This keeps things organized.

2️⃣ Download a FreeCAD icon

Example:

wget https://raw.githubusercontent.com/FreeCAD/FreeCAD/main/src/Gui/Icons/freecad.svg -O ~/Applications/freecad.svg

3️⃣ Create a desktop launcher

Create the launcher file:

nano ~/.local/share/applications/freecad.desktop

Paste this:

[Desktop Entry]
Name=FreeCAD 1.0
Comment=3D Parametric CAD Modeler
Exec=/home/YOURUSERNAME/Applications/FreeCAD_1.0.0-Linux-x86_64.AppImage
Icon=/home/YOURUSERNAME/Applications/freecad.svg
Terminal=false
Type=Application
Categories=Graphics;Engineering;
StartupNotify=true

Replace YOURUSERNAME with your Linux username.

Save and exit:

- Ctrl + O
- Enter
- Ctrl + X

4️⃣ Make it executable

chmod +x ~/.local/share/applications/freecad.desktop

5️⃣ Refresh desktop database

Usually not required, but safe:

update-desktop-database ~/.local/share/applications

✅ Now FreeCAD will appear in your application launcher/menu like a normal installed program.

💡 Optional nice improvement

You can also allow the launcher to appear on the desktop:

cp ~/.local/share/applications/freecad.desktop ~/Desktop/
chmod +x ~/Desktop/freecad.desktop

🔥 If you want, I can also show you an automatic AppImage manager (AppImageLauncher) that integrates any AppImage automatically into the system menus with one click. It makes AppImages behave like normal installed apps.

# LLM request

1) Download the AppImage

--2026-03-09 12:46:27--

https://github.com/FreeCAD/FreeCAD/releases/download/1.0.2/FreeCAD_1.0.2-Linux-x86_64.AppImage

Resolving github.com (github.com)... 140.82.121.3

Connecting to github.com (github.com)|140.82.121.3|:443... connected. HTTP request sent, awaiting response... 404 Not Found

2026-03-09 12:46:28 ERROR 404: Not Found.

# LLM resopnse

The Linux AppImages for FreeCAD 1.0.2 are not in the FreeCAD/FreeCAD repository.
They are published in a different repository called FreeCAD/FreeCAD-Bundle.

Also, the filename changed slightly.

Correct download URL

Use this instead:

https://github.com/FreeCAD/FreeCAD-Bundle/releases/download/1.0.2/FreeCAD_1.0.2-conda-Linux-x86_64-py311.AppImage

Example command:

wget -O FreeCAD_1.0.2.AppImage \
https://github.com/FreeCAD/FreeCAD-Bundle/releases/download/1.0.2/FreeCAD_1.0.2-conda-Linux-x86_64-py311.AppImage

The asset name includes:

conda-Linux-x86_64-py311

because the official AppImage is built with a conda Python environment.

Recommended fix in your script

Change this line:

wget -O "$APPIMAGE" \
https://github.com/FreeCAD/FreeCAD/releases/download/1.0.2/FreeCAD_1.0.2-Linux-x86_64.AppImage

to:

wget -O "$APPIMAGE" \
https://github.com/FreeCAD/FreeCAD-Bundle/releases/download/1.0.2/FreeCAD_1.0.2-conda-Linux-x86_64-py311.AppImage

Optional improvement (very useful)

Right now your script breaks whenever the version changes.
A nicer installer automatically downloads the latest release of FreeCAD.

If you want, I can show you a small Bash trick using the GitHub API so your script always installs the newest version automatically (no hardcoding versions). It only adds about 4 lines to your script and makes it much more robust. 🚀

I-MAP: Logbook (AI Usage) TSMK

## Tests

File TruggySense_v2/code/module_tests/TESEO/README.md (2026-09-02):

# TESEO-LIV3F GPS on Teensy 4.1 — PlatformIO

## Wiring

### UART (recommended — simpler, no dummy-byte filtering)
| TESEO-LIV3F pin | Teensy 4.1 pin |
|---|---|
| TX | RX1 (pin 0) |
| RX | TX1 (pin 1) |
| VCC | 3.3V |
| GND | GND |
| NRESET (opt.) | Pin 2 |

### I2C
| TESEO-LIV3F pin | Teensy 4.1 pin |
|---|---|
| SDA | SDA (pin 18) |
| SCL | SCL (pin 19) |
| VCC | 3.3V |
| GND | GND |
| NRESET (opt.) | Pin 2 |

> Note: TESEO-LIV3F is a 3.3V device. Teensy 4.1 GPIO is also 3.3V — no level shifting needed.
> Add 4.7kΩ pull-ups on SDA/SCL to 3.3V for I2C.

## Building
Select your interface in `platformio.ini` by uncommenting the right build flag:
- `-DUSE_UART` for UART mode
- `-DUSE_I2C` for I2C mode

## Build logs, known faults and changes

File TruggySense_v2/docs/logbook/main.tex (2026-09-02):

\documentclass[12pt,a4paper,twoside]{article}

% Packages
\usepackage{graphicx}   % For including images
\usepackage{geometry}   % For margin control
\usepackage{ragged2e}   % For left/right alignment
\usepackage{titling}    % Allows retrieving \title, \author, \subtitle
\usepackage{titlesec}   % For subtitle support
\usepackage{mathptmx}   % For common fonts
\usepackage{lastpage}   % Defines the total amount of pages
\usepackage{listings}   % For code use
\usepackage{xcolor}

\usepackage[english]{babel} % load the proper language(s)
\usepackage[backref,hyperindex=true,pagebackref=true]{hyperref} % generate PDFs with clickable links
\usepackage[export]{adjustbox} % change the default image alignment

\usepackage{booktabs}
\usepackage{fancyhdr}
\usepackage{tabularray}

\graphicspath{{./images/}} % Path for images

% ---------------------- Document variables ----------------------
\newcommand{\documenttitle}{II-MAP:\@ LOGBOOK}
\newcommand{\documentsubtitle}{Universiteit van Antwerpen
Toegepaste Ingenieurswetenschappen (Elektronica-ICT)}
\newcommand{\documentauthor}{Kramp Thomas}

% ---------------------- Page layout ----------------------
\geometry{top=2cm,left=2cm,right=2cm,bottom=2cm}
\AddToHook{cmd/section/before}{\clearpage}

% ---------------------- Header and footer layout ----------------------
\pagestyle{empty}               % temporarily for cover page
\setlength{\footskip}{1.2cm}    % Footer spacing
\fancypagestyle{mainstyle}{     % Define the fancy book-style footer
    \fancyhf{}
    \fancyhead[LE,LO]{\documenttitle}   % title to left of all page headers
    \fancyfoot[LE]{\thepage\ of\ \pageref*{LastPage}} % left footer on even pages
    \fancyfoot[RO]{\thepage\ of\ \pageref*{LastPage}} % right footer on odd pages
    \renewcommand{\headrulewidth}{0pt}
    \renewcommand{\footrulewidth}{0pt}
}

% ---------------------- Hyperlink setup ----------------------
\hypersetup{
    colorlinks=true,
    linkcolor=blue,
    filecolor=magenta,      
    urlcolor=cyan,
}
\lstset{escapeinside={(*@}{@*)}}

% ---------------------- Listings setup ----------------------
\usepackage{enumitem}
\usepackage{array}
\setlist[itemize]{
    label=--,
    topsep=0pt,
    itemsep=0pt,
    parsep=0pt,
    partopsep=0pt
}

% ---------------------- Document ----------------------
\begin{document}

\thispagestyle{empty}

% Cover page
{\Huge\bfseries \documenttitle\par}
\vspace{0.5cm}
{\large \documentauthor\par}
\vspace{5.3cm}

\vfill
\begin{flushright}
    {\Large \documentsubtitle}
\end{flushright}

% Start page count from the second page
\thispagestyle{empty}   % cover page has no number
\clearpage              % go to page 2
\pagestyle{fancy}       % make sure page 2+ use fancy headers/footers
\pagestyle{mainstyle}   % enable mirrored pages

% ---------------------- MAIN CONTENT ----------------------
\begin{table}[!t]
	\centering
	\begin{tabular}{c p{14cm}}
		\toprule
			Date & Action \\
		\midrule
            % Week 1
            % --------------------------------------------
			\raisebox{-3.33mm}{05/01/2026} & 
            \begin{itemize}
                \item Setup docs: Paper, Portfolio, Logbook \& Reports
                \item Add LLC review to Portfolio
            \end{itemize} \\

			\raisebox{-3.33mm}{07/01/2026} & 
            \begin{itemize}
                \item Create LLC schematic
            \end{itemize} \\

			\raisebox{-3.33mm}{09/01/2026} & 
            \begin{itemize}
                \item Create LLC PCB
            \end{itemize} \\

			\raisebox{-3.33mm}{11/01/2026} & 
            \begin{itemize}
                \item Continue working on LLC PCB
            \end{itemize} \\

        \midrule
            % Week 2
            % --------------------------------------------

        \midrule
            % Week 3
            % --------------------------------------------
			\raisebox{-3.33mm}{19/01/2026} & 
            \begin{itemize}
                \item Add new LLC review to portfolio (no more JLCPCB)
                \item Disassemble TruggySense v1
                \item Add temperature sensor review to portfolio
                \item Create and finish temperature sensor schematic and PCB
            \end{itemize} \\

			\raisebox{-3.33mm}{20/01/2026} & 
            \begin{itemize}
                \item Figured out the external ADC usage (conflicting documentation)
            \end{itemize} \\

			\raisebox{-3.33mm}{21/01/2026} & 
            \begin{itemize}
                \item Made changes to the temperature sensor schematic and PCB to adhere to school components
                \item Added the defense of ADC usage in the portfolio.
                \item Started on figuring out the power supply (missing documentation).
            \end{itemize} \\

        \midrule
            % Week 4
            % --------------------------------------------
			\raisebox{-3.33mm}{23/01/2026} & 
            \begin{itemize}
                \item Finished figuring out the power supply (missing documentation).
                \item Made a schematic of missing power supply documentation.
            \end{itemize} \\

			\raisebox{-3.33mm}{25/01/2026} & 
            \begin{itemize}
                \item Added the defense for the HLC, Motion sensor, Wheel actuator and Ampere meter in the portfolio.
                \item Started on the defense for the Position sensor, RC controller and wifi in the portfolio.
                \item Worked on the defense of the supply and DC/DC converter in the portfolio.
                \item Added power use expectation table.
                \item Added I²C address use table.
            \end{itemize} \\

			\raisebox{-3.33mm}{27/01/2026} & 
            \begin{itemize}
                \item Added the defense for the Motion sensor, Position sensor in the portfolio.
                \item Added reasoning of portfolio v1 to portfolio v2.
                \item Added Kiwi, Conrad and Antratek to each stock table.
                \item Updated power use expectation table.
                \item Updated I²C address use table.
            \end{itemize} \\

			\raisebox{-3.33mm}{01/02/2026} & 
            \begin{itemize}
                \item Completed the defense for the LLC, Long range communication and Current sensor in the portfolio.
            \end{itemize} \\

        \midrule
            % Week 5
            % --------------------------------------------
			\raisebox{-3.33mm}{02/02/2026} & 
            \begin{itemize}
                \item Added defense for the DC/DC converter to the portfolio.
                \item Added Otronic to the stock tables.
                \item Made it so only two of the following web-shops show: Kiwi, Conrad, Antratek and Otronic.
                \item Changed the long-range communication defense based on feedback.
            \end{itemize} \\

			\raisebox{-3.33mm}{03/02/2026} & 
            \begin{itemize}
                \item Added Shunt resistor calculations to the current meter defense.
                \item Create a schematic and PCB for the Power Supply PCB.
            \end{itemize} \\
	\end{tabular}
\end{table}

\begin{table}[!t]
	\centering
	\begin{tabular}{c p{14cm}}

			\raisebox{-3.33mm}{06/02/2026} & 
            \begin{itemize}
                \item Added KiCAD guides.
                \item Cleaned up and sorted old .stl files and their FreeCAD/OpenSCAD file.
                \item Created an overview of all external libraries and their references.
                \item Created a defense for and made changes to the IO protection circuits.
            \end{itemize} \\

			\raisebox{-3.33mm}{08/02/2026} & 
            \begin{itemize}
                \item Recreated the PCB layout for the nRF24L01 and PIM448 modules.
                \item Recreated the PCB for the INA219 and LM2596 modules.
                \item Continued on the IO protection defense.
            \end{itemize} \\

        \midrule
            % Week 6
            % --------------------------------------------
			\raisebox{-3.33mm}{09/02/2026} & 
            \begin{itemize}
                \item Edited the IO protection circuits based on feedback.
                \item Created a CSV for the low-pass filter/voltage divider circuit.
                \item Created a schematic for the position module.
            \end{itemize} \\

        \midrule
            % Week 7
            % --------------------------------------------
			\raisebox{-3.33mm}{16/02/2026} & 
            \begin{itemize}
                \item Created a PCB for the position module.
                \item Started on the logic PCB schematic.
            \end{itemize} \\

			\raisebox{-3.33mm}{18/02/2026} & 
            \begin{itemize}
                \item Continued on the logic PCB schematic.
            \end{itemize} \\

			\raisebox{-3.33mm}{19/02/2026} & 
            \begin{itemize}
                \item Finished the logic PCB schematic.
                \item Started on the logic PCB design.
            \end{itemize} \\

			\raisebox{-3.33mm}{20/02/2026} & 
            \begin{itemize}
                \item Continued on the logic PCB design.
            \end{itemize} \\

        \midrule
            % Week 8
            % --------------------------------------------
			\raisebox{-3.33mm}{24/02/2026} & 
            \begin{itemize}
                \item Made the powerpoint for the first presentation.
            \end{itemize} \\

			\raisebox{-3.33mm}{25/02/2026} & 
            \begin{itemize}
                \item Gave the first progress report presentation.
            \end{itemize} \\

			\raisebox{-3.33mm}{26/02/2026} & 
            \begin{itemize}
                \item Continued on the logic PCB design.
            \end{itemize} \\

			\raisebox{-3.33mm}{27/02/2026} & 
            \begin{itemize}
                \item Finished the logic PCB design.
            \end{itemize} \\

			\raisebox{-3.33mm}{01/03/2026} & 
            \begin{itemize}
                \item Generated all the gerber, drill and BOM files.
                \item Listed all parts with stocking urls for order.
            \end{itemize} \\

        \midrule
            % Week 9
            % --------------------------------------------
			\raisebox{-3.33mm}{02/03/2026} & 
            \begin{itemize}
                \item Installed platformIO.
                \item Figured out how to create a Teensy project via PlatformIO.
                \item Documented process.
            \end{itemize} \\

			\raisebox{-3.33mm}{05/03/2026} & 
            \begin{itemize}
                \item Created test code for Teensy 4.1, I2C interface, INA219.
                \item Created simple libraries for I2C interface and INA219.
            \end{itemize} \\

			\raisebox{-3.33mm}{06/03/2026} & 
            \begin{itemize}
                \item Created test code for SD-Card.
                \item Tried to make test code for nRF24L01, FS-X6B and ACS758; but couldn't due to insufficient resources.
                      Found compatible libraries that are ready for testing.
                \item Tested the FlySky remotes and removed any faults.
            \end{itemize} \\

            \raisebox{-3.33mm}{06/03/2026} & 
            \begin{itemize}
                \item Figured out how to use FreeCAD and started its guide.
            \end{itemize} \\

        \midrule
            % Week 10
            % --------------------------------------------
            \raisebox{-3.33mm}{09/03/2026} & 
            \begin{itemize}
                \item Cleaned up the old 3D-design sketches.
                \item Edited the old 3D-design sketches.
            \end{itemize} \\

            \raisebox{-3.33mm}{10/03/2026} & 
            \begin{itemize}
                \item Edited the old 3D-design sketches.
                \item Created a .dxf file for the new lasercut baseplate.
            \end{itemize} \\
	\end{tabular}
\end{table}

\begin{table}[!t]
	\centering
	\begin{tabular}{c p{14cm}}

            \raisebox{-3.33mm}{15/03/2026} & 
            \begin{itemize}
                \item Edited the old 3D-design sketches.
                \item Started with ROS2 \& micro-ROS implementation (not functioning).
                \item Started working with Nvidia Jetson Nano (not functioning).
            \end{itemize} \\

        \midrule
            % Week 11
            % --------------------------------------------
            \raisebox{-3.33mm}{16/03/2026} & 
            \begin{itemize}
                \item Printed all the finished 3D-prints.
                \item Continued to work on the Nvidia Jetson Nano (not functioning).
            \end{itemize} \\

            \raisebox{-3.33mm}{17/03/2026} & 
            \begin{itemize}
                \item Got the Nvidia Jetson Nano to work.
                \item Continued work on the ROS2 \& micro-ROS implementation (not functioning).
            \end{itemize} \\

            \raisebox{-3.33mm}{18/03/2026} & 
            \begin{itemize}
                \item Lasercut the base plate.
                \item Made changes to the new 3D-design sketches so they fit the baseplate.
            \end{itemize} \\

            \raisebox{-3.33mm}{20/03/2026} & 
            \begin{itemize}
                \item Got a base implementation of ROS2 \& micro-ROS working between the Teensy 4.1 and my personal laptop.
            \end{itemize} \\

            \raisebox{-3.33mm}{21/03/2026} & 
            \begin{itemize}
                \item Updated AI-usage documentation.
            \end{itemize} \\

        \midrule
            % Week 12
            % --------------------------------------------
            \raisebox{-3.33mm}{24/03/2026} & 
            \begin{itemize}
                \item Documented the complete KiCAD section.
            \end{itemize} \\

            \raisebox{-3.33mm}{26/03/2026} & 
            \begin{itemize}
                \item Created a diagram of the power layout.
            \end{itemize} \\

            \raisebox{-3.33mm}{27/03/2026} & 
            \begin{itemize}
                \item Fetched the components and PCBs.
                \item Assembled the power board and temperature sensor PCBs.
            \end{itemize} \\

            \raisebox{-3.33mm}{28/03/2026} & 
            \begin{itemize}
                \item Documented the complete FreeCAD and Metalcut sections.
                \item Updated the ROS integration of the Software chapter for both the Teensy and the Jetson.
            \end{itemize} \\

            \raisebox{-3.33mm}{29/03/2026} & 
            \begin{itemize}
                \item Created test code for LM75 and PIM448.
                \item Created simple libraries for LM75 and PIM448.
            \end{itemize} \\

        \midrule
            % Week 13
            % --------------------------------------------
            \raisebox{-3.33mm}{30/03/2026} & 
            \begin{itemize}
                \item Assembled the first temperature sensor board.
                \item Assembled the power board.
                \item Started assembly of the logic board.
                \item Tested the temperature sensor.
            \end{itemize} \\

            \raisebox{-3.33mm}{31/03/2026} & 
            \begin{itemize}
                \item Finished assembly of the logic board.
                \item Tested the power distribution of the logic board.
            \end{itemize} \\

            \raisebox{-3.33mm}{01/04/2026} & 
            \begin{itemize}
                \item Assembled the GNSS/GPS module.
                \item Assembled the remaining temperature sensor boards.
                \item Created a PWM test.
                \item Tested the INA219, LM2596, PIM448.
            \end{itemize} \\

            \raisebox{-3.33mm}{03/04/2026} & 
            \begin{itemize}
                \item Created a servo script.
                \item Tested the remaining temperature sensors and servo.
                \item Tested the power cycle between power board, TMDC and logic board.
                \item Continued documentation of design.
                \item Documented PCB faults.
            \end{itemize} \\

        \midrule
            % Week 14
            % --------------------------------------------

        \midrule
            % Week 15
            % --------------------------------------------
            \raisebox{-3.33mm}{13/04/2026} & 
            \begin{itemize}
                \item Tested the voltage followers.
                \item Found a fault with the buffer circuit.
                \item Created a test for USB. --> Blew up my PC.
            \end{itemize} \\
	\end{tabular}
\end{table}

\begin{table}[!t]
	\centering
	\begin{tabular}{c p{14cm}}

            \raisebox{-3.33mm}{15/04/2026} & 
            \begin{itemize}
                \item Reinstalled everything on new PC.
                \item Tested old functioning sketches, to make sure board was still functioning.
            \end{itemize} \\

            \raisebox{-3.33mm}{16/04/2026} & 
            \begin{itemize}
                \item Created and tested the FS-X6B sketch.
                \item Created and tested the Hall-sensor sketch.
            \end{itemize} \\
            
            \raisebox{-3.33mm}{17/04/2026} & 
            \begin{itemize}
                \item Created and tested the high-current sensing.
                \item Tested the self-made GPS (not functioning).
            \end{itemize} \\

            \raisebox{-3.33mm}{18/04/2026} & 
            \begin{itemize}
                \item Found the motor ECS startup sequence.
                \item Fixed the motor sketch.
                \item Created a working drive sketch.
            \end{itemize} \\

        \midrule
            % Week 16
            % --------------------------------------------
            \raisebox{-3.33mm}{20/04/2026} & 
            \begin{itemize}
                \item Created the main sketch.
                \item Implemented the remote control in the main sketch.
                \item Implemented the steering servo in the main sketch.
            \end{itemize} \\

            \raisebox{-3.33mm}{21/04/2026} & 
            \begin{itemize}
                \item Implemented the motor control in the main sketch.
                \item Implemented the voltage reading in the main sketch.
            \end{itemize} \\

            \raisebox{-3.33mm}{22/04/2026} & 
            \begin{itemize}
                \item Implemented a global debugging serial in the main sketch.
                \item Implemented the encoder in the main sketch.
                \item Tried to implement the high current reading in the main sketch.
            \end{itemize} \\

            \raisebox{-3.33mm}{23/04/2026} & 
            \begin{itemize}
                \item Implemented the high current reading in the main sketch.
                \item Implemented the low current reading in the main sketch.
                \item Implemented the temperature sensor in the main sketch.
            \end{itemize} \\

            \raisebox{-3.33mm}{24/04/2026} & 
            \begin{itemize}
                \item Implemented the indicator led in the main sketch.
                \item Implemented the cooling fan in the main sketch.
                \item Implemented the motion sensor in the main sketch.
            \end{itemize} \\

            \raisebox{-3.33mm}{25/04/2026} & 
            \begin{itemize}
                \item Tried to create a GPS sketch.
            \end{itemize} \\

            \raisebox{-3.33mm}{26/04/2026} & 
            \begin{itemize}
                \item Tried to make a long range communication sketch.
            \end{itemize} \\

        \midrule
            % Week 17
            % --------------------------------------------
            \raisebox{-3.33mm}{27/04/2026} & 
            \begin{itemize}
                \item Made a long range communication TX and RX sketch.
                \item Made a long range communication RX module.
                \item Implemented the long range TX communication in the main sketch.
            \end{itemize} \\

            \raisebox{-3.33mm}{28/04/2026} & 
            \begin{itemize}
                \item Implemented the SD-logging into the main sketch.
                \item Started to implement the schedular into the main sketch.
            \end{itemize} \\

            \raisebox{-3.33mm}{29/04/2026} & 
            \begin{itemize}
                \item Continued to implement the schedular into the main sketch.
            \end{itemize} \\

            \raisebox{-3.33mm}{30/04/2026} & 
            \begin{itemize}
                \item Finished to implement the schedular into the main sketch.
                \item Debugged the main sketch for any mistakes.
            \end{itemize} \\

            \raisebox{-3.33mm}{01/05/2026} & 
            \begin{itemize}
                \item Debugged the main sketch for any mistakes.
                \item Made a functioning GPS sketch.
                \item Tried to implement micro-ROS into the main sketch.
            \end{itemize} \\

            \raisebox{-3.33mm}{02/05/2026} & 
            \begin{itemize}
                \item Implemented the GPS into the main sketch.
                \item Tested the complete system and found bugs.
                \item Removed the bugs.
            \end{itemize} \\
	\end{tabular}
\end{table}

\begin{table}[!t]
	\centering
	\begin{tabular}{c p{14cm}}

            \raisebox{-3.33mm}{03/05/2026} &
            \begin{itemize}
                \item Implemented .csv and .json logging via the SD-Card (besides .bin).
                \item Tested the complete system and found bugs.
                \item Removed the bugs.
                \item Started on the academic paper.
            \end{itemize} \\

        \midrule
            % Week 18
            % --------------------------------------------
            \raisebox{-3.33mm}{04/05/2026} & 
            \begin{itemize}
                \item Continued working on the academic paper.
            \end{itemize} \\

            \raisebox{-3.33mm}{05/05/2026} & 
            \begin{itemize}
                \item Continued working on the academic paper.
            \end{itemize} \\

            \raisebox{-3.33mm}{06/05/2026} & 
            \begin{itemize}
                \item Continued working on the academic paper.
            \end{itemize} \\

            \raisebox{-3.33mm}{07/05/2026} & 
            \begin{itemize}
                \item Continued working on the academic paper.
                \item Went on the RC Racing Fun track to test the system and gather data.
                \item Replaced the broken Servo.
            \end{itemize} \\

            \raisebox{-3.33mm}{08/05/2026} & 
            \begin{itemize}
                \item Continued working on the academic paper.
                \item Went on the RC Racing Fun track to test the system and gather data.
            \end{itemize} \\

            \raisebox{-3.33mm}{09/05/2026} & 
            \begin{itemize}
                \item Continued working on the academic paper.
                \item Fixed the GPS baud rate, by programming the module inside the firmware.
                \item Started on working on the next PCB.
                \item Went on the RC Racing Fun track to test the system and gather data.
            \end{itemize} \\

            \raisebox{-3.33mm}{10/05/2026} &
            \begin{itemize}
                \item Continued working on the academic paper.
                \item Attempted to fix the wheel encoder bug (untested on the track).
            \end{itemize} \\

        \midrule
            % Week 19
            % --------------------------------------------
            \raisebox{-3.33mm}{11/05/2026} &
            \begin{itemize}
                \item Fixed the wheel encoder bug.
                \item Fixed one of the broken servos.
                \item Worked on the documentation.
                \item Started on the finalized PCB designs (temperature sensor and supply board).
            \end{itemize} \\

            \raisebox{-3.33mm}{12/05/2026} &
            \begin{itemize}
                \item Worked on the documentation.
                \item Continued on the finalized PCB designs (logic board).
                \item Went on the RC Racing Fun track to test the system and gather data, but couldn't due to faulty GPS antenna.
            \end{itemize} \\

            \raisebox{-3.33mm}{13/05/2026} &
            \begin{itemize}
                \item Worked on the documentation.
                \item Continued on the finalized PCB designs (logic board).
            \end{itemize} \\

            \raisebox{-3.33mm}{14/05/2026} &
            \begin{itemize}
                \item Worked on the documentation.
                \item Finished the finalized PCB designs (logic board).
                \item Started adding documentation to the code.
            \end{itemize} \\

            \raisebox{-3.33mm}{15/05/2026} &
            \begin{itemize}
                \item Generalized the motor control code (now includes both ESC and SERVO).
                \item Finished adding documentation to the code.
                \item Went on the RC Racing Fun track to test the system and gather data, but couldn't due to the state of the track and weather conditions.
                \item Fixed problems caused by driving on a less than ideal track.
            \end{itemize} \\

            \raisebox{-3.33mm}{16/05/2026} &
            \begin{itemize}
                \item Added more functionality to the SD-logging.
                \item Tested the complete system (in my front yard).
            \end{itemize} \\

            \raisebox{-3.33mm}{17/05/2026} &
            \begin{itemize}
                \item Went on the RC Racing Fun track to test the system and gather data, got base data that proves functionality, 
                      but couldn't continue due to the state of the track and weather conditions.
                \item Fixed problems caused by driving on a less than ideal track.
            \end{itemize} \\
	\end{tabular}
\end{table}

\begin{table}[!t]
	\centering
	\begin{tabular}{c p{14cm}}

        \midrule
            % Week 20
            % --------------------------------------------
            \raisebox{-3.33mm}{18/05/2026} &
            \begin{itemize}
                \item Worked on the academic paper.
                \item Worked on the documentation.
            \end{itemize} \\

            \raisebox{-3.33mm}{19/05/2026} &
            \begin{itemize}
                \item Worked on the academic paper.
                \item Worked on the documentation.
            \end{itemize} \\

            \raisebox{-3.33mm}{20/05/2026} &
            \begin{itemize}
                \item Worked on the documentation.
            \end{itemize} \\

            \raisebox{-3.33mm}{21/05/2026} &
            \begin{itemize}
                \item Re-read and corrected the academic paper.
                \item Worked on the documentation.
            \end{itemize} \\

            \raisebox{-3.33mm}{22/05/2026} &
            \begin{itemize}
                \item Went on the RC Racing Fun track to test the system and gather data.
                \item Implemented the new data into and finished the academic paper.
            \end{itemize} \\

            \raisebox{-3.33mm}{23/05/2026} &
            \begin{itemize}
                \item Re-read and corrected the academic paper.
                \item Worked on the documentation.
            \end{itemize} \\

            \raisebox{-3.33mm}{24/05/2026} &
            \begin{itemize}
                \item Re-read and corrected the academic paper.
                \item Finished on the documentation.
            \end{itemize} \\
		\bottomrule
	\end{tabular}
\end{table}

\end{document}

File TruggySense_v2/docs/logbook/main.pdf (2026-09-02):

# II-MAP: LOGBOOK

### Kramp Thomas

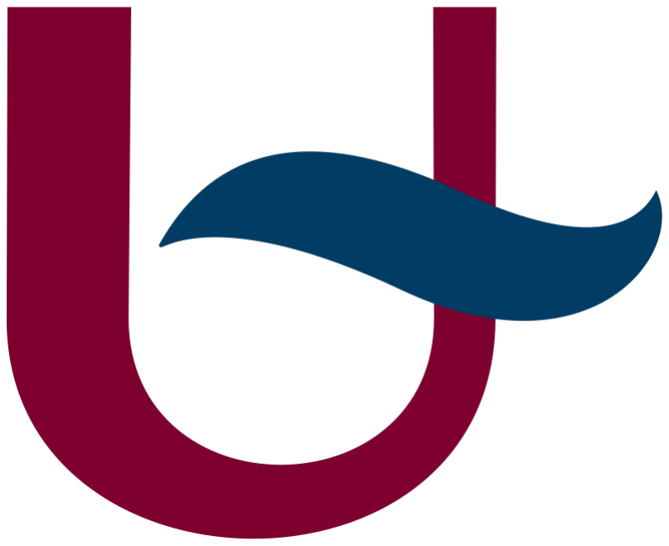
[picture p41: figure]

## Universiteit van Antwerpen Toegepaste Ingenieurswetenschappen (Elektronica-ICT)

II-MAP: LOGBOOK

Date | Action
05/01/2026 | – Setup docs: Paper, Portfolio, Logbook & Reports – Add LLC review to Portfolio
07/01/2026 | – Create LLC schematic
09/01/2026 | – Create LLC PCB
11/01/2026 | – Continue working on LLC PCB
19/01/2026 | – Add new LLC review to portfolio (no more JLCPCB) – Disassemble TruggySense v1 – Add temperature sensor review to portfolio – Create and finish temperature sensor schematic and PCB
20/01/2026 | – Figured out the external ADC usage (conflicting documentation)
21/01/2026 | – Made changes to the temperature sensor schematic and PCB to adhere to school components – Added the defense of ADC usage in the portfolio. – Started on figuring out the power supply (missing documentation).
23/01/2026 | – Finished figuring out the power supply (missing documentation). – Made a schematic of missing power supply documentation.
25/01/2026 | – Added the defense for the HLC, Motion sensor, Wheel actuator and Ampere meter in the portfolio. – Started on the defense for the Position sensor, RC controller and wifi in the portfolio. – Worked on the defense of the supply and DC/DC converter in the portfolio. – Added power use expectation table. – Added I²C address use table.
27/01/2026 | – Added the defense for the Motion sensor, Position sensor in the portfolio. – Added reasoning of portfolio v1 to portfolio v2. – Added Kiwi, Conrad and Antratek to each stock table. – Updated power use expectation table. – Updated I²C address use table.
01/02/2026 | – Completed the defense for the LLC, Long range communication and Current sensor in the portfolio.
02/02/2026 | – Added defense for the DC/DC converter to the portfolio. – Added Otronic to the stock tables. – Made it so only two of the following web-shops show: Kiwi, Conrad, Antratek and Otronic. – Changed the long-range communication defense based on feedback.
03/02/2026 | – Added Shunt resistor calculations to the current meter defense. – Create a schematic and PCB for the Power Supply PCB.

06/02/2026 | – Added KiCAD guides. – Cleaned up and sorted old .stl files and their FreeCAD/OpenSCAD file. – Created an overview of all external libraries and their references. – Created a defense for and made changes to the IO protection circuits.
08/02/2026 | – Recreated the PCB layout for the nRF24L01 and PIM448 modules. – Recreated the PCB for the INA219 and LM2596 modules. – Continued on the IO protection defense.
09/02/2026 | – Edited the IO protection circuits based on feedback. – Created a CSV for the low-pass filter/voltage divider circuit. – Created a schematic for the position module.
16/02/2026 | – Created a PCB for the position module. – Started on the logic PCB schematic.
18/02/2026 | – Continued on the logic PCB schematic.
19/02/2026 | – Finished the logic PCB schematic. – Started on the logic PCB design.
20/02/2026 | – Continued on the logic PCB design.
24/02/2026 | – Made the powerpoint for the first presentation.
25/02/2026 | – Gave the first progress report presentation.
26/02/2026 | – Continued on the logic PCB design.
27/02/2026 | – Finished the logic PCB design.
01/03/2026 | – Generated all the gerber, drill and BOM files. – Listed all parts with stocking urls for order.
02/03/2026 | – Installed platformIO. – Figured out how to create a Teensy project via PlatformIO. – Documented process.
05/03/2026 | – Created test code for Teensy 4.1, I2C interface, INA219. – Created simple libraries for I2C interface and INA219.
06/03/2026 | – Created test code for SD-Card. – Tried to make test code for nRF24L01, FS-X6B and ACS758; but couldn’t due to insufficient resources. Found compatible libraries that are ready for testing. – Tested the FlySky remotes and removed any faults.
06/03/2026 | – Figured out how to use FreeCAD and started its guide.
09/03/2026 | – Cleaned up the old 3D-design sketches. – Edited the old 3D-design sketches.
10/03/2026 | – Edited the old 3D-design sketches. – Created a .dxf file for the new lasercut baseplate.

15/03/2026 | – Edited the old 3D-design sketches. – Started with ROS2 & micro-ROS implementation (not functioning). – Started working with Nvidia Jetson Nano (not functioning).
16/03/2026 | – Printed all the finished 3D-prints. – Continued to work on the Nvidia Jetson Nano (not functioning).
17/03/2026 | – Got the Nvidia Jetson Nano to work. – Continued work on the ROS2 & micro-ROS implementation (not function- ing).
18/03/2026 | – Lasercut the base plate. – Made changes to the new 3D-design sketches so they fit the baseplate.
20/03/2026 | – Got a base implementation of ROS2 & micro-ROS working between the Teensy 4.1 and my personal laptop.
21/03/2026 | – Updated AI-usage documentation.
24/03/2026 | – Documented the complete KiCAD section.
26/03/2026 | – Created a diagram of the power layout.
27/03/2026 | – Fetched the components and PCBs. – Assembled the power board and temperature sensor PCBs.
28/03/2026 | – Documented the complete FreeCAD and Metalcut sections. – Updated the ROS integration of the Software chapter for both the Teensy and the Jetson.
29/03/2026 | – Created test code for LM75 and PIM448. – Created simple libraries for LM75 and PIM448.
30/03/2026 | – Assembled the first temperature sensor board. – Assembled the power board. – Started assembly of the logic board. – Tested the temperature sensor.
31/03/2026 | – Finished assembly of the logic board. – Tested the power distribution of the logic board.
01/04/2026 | – Assembled the GNSS/GPS module. – Assembled the remaining temperature sensor boards. – Created a PWM test. – Tested the INA219, LM2596, PIM448.
03/04/2026 | – Created a servo script. – Tested the remaining temperature sensors and servo. – Tested the power cycle between power board, TMDC and logic board. – Continued documentation of design. – Documented PCB faults.
13/04/2026 | – Tested the voltage followers. – Found a fault with the buffer circuit. – Created a test for USB. –¿ Blew up my PC.

15/04/2026 | – Reinstalled everything on new PC. – Tested old functioning sketches, to make sure board was still functioning.
16/04/2026 | – Created and tested the FS-X6B sketch. – Created and tested the Hall-sensor sketch.
17/04/2026 | – Created and tested the high-current sensing. – Tested the self-made GPS (not functioning).
18/04/2026 | – Found the motor ECS startup sequence. – Fixed the motor sketch. – Created a working drive sketch.
20/04/2026 | – Created the main sketch. – Implemented the remote control in the main sketch. – Implemented the steering servo in the main sketch.
21/04/2026 | – Implemented the motor control in the main sketch. – Implemented the voltage reading in the main sketch.
22/04/2026 | – Implemented a global debugging serial in the main sketch. – Implemented the encoder in the main sketch. – Tried to implement the high current reading in the main sketch.
23/04/2026 | – Implemented the high current reading in the main sketch. – Implemented the low current reading in the main sketch. – Implemented the temperature sensor in the main sketch.
24/04/2026 | – Implemented the indicator led in the main sketch. – Implemented the cooling fan in the main sketch. – Implemented the motion sensor in the main sketch.
25/04/2026 | – Tried to create a GPS sketch.
26/04/2026 | – Tried to make a long range communication sketch.
27/04/2026 | – Made a long range communication TX and RX sketch. – Made a long range communication RX module. – Implemented the long range TX communication in the main sketch.
28/04/2026 | – Implemented the SD-logging into the main sketch. – Started to implement the schedular into the main sketch.
29/04/2026 | – Continued to implement the schedular into the main sketch.
30/04/2026 | – Finished to implement the schedular into the main sketch. – Debugged the main sketch for any mistakes.
01/05/2026 | – Debugged the main sketch for any mistakes. – Made a functioning GPS sketch. – Tried to implement micro-ROS into the main sketch.
02/05/2026 | – Implemented the GPS into the main sketch. – Tested the complete system and found bugs. – Removed the bugs.

03/05/2026 | – Implemented .csv and .json logging via the SD-Card (besides .bin). – Tested the complete system and found bugs. – Removed the bugs. – Started on the academic paper.
04/05/2026 | – Continued working on the academic paper.
05/05/2026 | – Continued working on the academic paper.
06/05/2026 | – Continued working on the academic paper.
07/05/2026 | – Continued working on the academic paper. – Went on the RC Racing Fun track to test the system and gather data. – Replaced the broken Servo.
08/05/2026 | – Continued working on the academic paper. – Went on the RC Racing Fun track to test the system and gather data.
09/05/2026 | – Continued working on the academic paper. – Fixed the GPS baud rate, by programming the module inside the firmware. – Started on working on the next PCB. – Went on the RC Racing Fun track to test the system and gather data.
10/05/2026 | – Continued working on the academic paper. – Attempted to fix the wheel encoder bug (untested on the track).
11/05/2026 | – Fixed the wheel encoder bug. – Fixed one of the broken servos. – Worked on the documentation. – Started on the finalized PCB designs (temperature sensor and supply board).
12/05/2026 | – Worked on the documentation. – Continued on the finalized PCB designs (logic board). – Went on the RC Racing Fun track to test the system and gather data, but couldn’t due to faulty GPS antenna.
13/05/2026 | – Worked on the documentation. – Continued on the finalized PCB designs (logic board).
14/05/2026 | – Worked on the documentation. – Finished the finalized PCB designs (logic board). – Started adding documentation to the code.
15/05/2026 | – Generalized the motor control code (now includes both ESC and SERVO). – Finished adding documentation to the code. – Went on the RC Racing Fun track to test the system and gather data, but couldn’t due to the state of the track and weather conditions. – Fixed problems caused by driving on a less than ideal track.
16/05/2026 | – Added more functionality to the SD-logging. – Tested the complete system (in my front yard).
17/05/2026 | – Went on the RC Racing Fun track to test the system and gather data, got base data that proves functionality, but couldn’t continue due to the state of the track and weather conditions. – Fixed problems caused by driving on a less than ideal track.

18/05/2026 | – Worked on the academic paper. – Worked on the documentation.
19/05/2026 | – Worked on the academic paper. – Worked on the documentation.
20/05/2026 | – Worked on the documentation.
21/05/2026 | – Re-read and corrected the academic paper. – Worked on the documentation.
22/05/2026 | – Went on the RC Racing Fun track to test the system and gather data. – Implemented the new data into and finished the academic paper.
23/05/2026 | – Re-read and corrected the academic paper. – Worked on the documentation.
24/05/2026 | – Re-read and corrected the academic paper. – Finished on the documentation.

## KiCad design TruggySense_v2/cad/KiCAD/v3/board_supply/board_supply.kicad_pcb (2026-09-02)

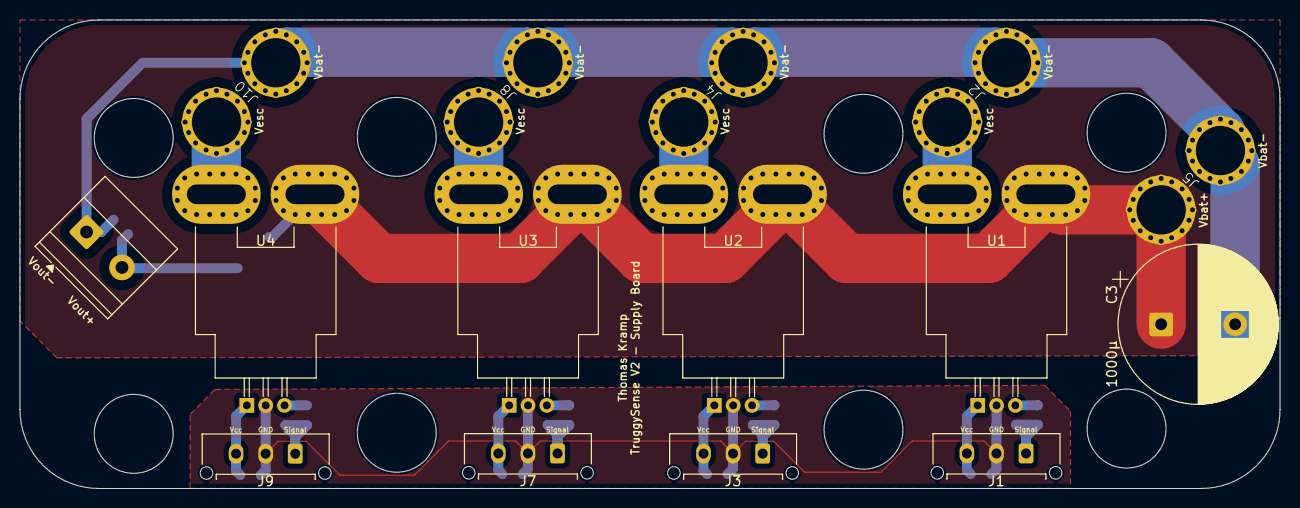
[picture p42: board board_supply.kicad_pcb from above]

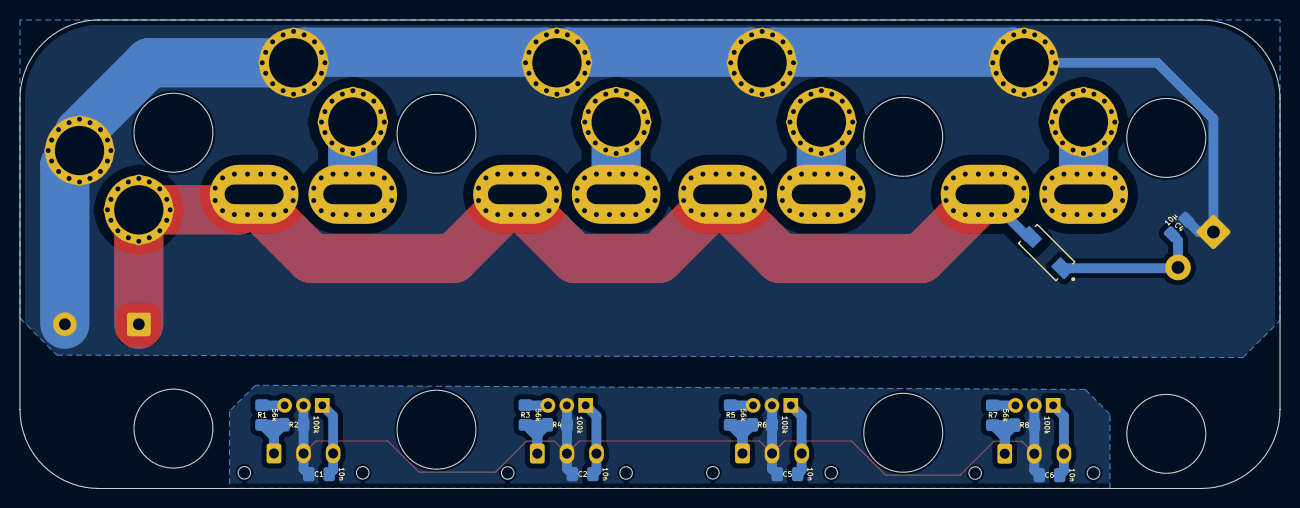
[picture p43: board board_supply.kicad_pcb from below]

Board: 6 copper layers, 127.8 x 47.5 mm, 29 parts (14 on the bottom side), 20 nets.

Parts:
C1, C2, C5, C6: 10n; C_0805_2012Metric_Pad1.18x1.45mm_HandSolder
C3: 1000µ; CP_Radial_D16.0mm_P7.50mm
C4: 10µ; C_0805_2012Metric_Pad1.18x1.45mm_HandSolder
D1: VSSAF5M10HM3; DIOM5226X100N
J1, J3, J7, J9: High_I_Sens; Molex_Micro-Fit_3.0_43650-0315_1x03_P3.00mm_Vertical
J2, J4, J8, J10: ESC; EC5_cable_pads
J5: BAT; EC5_cable_pads
J6: TMDC 20-2411; TerminalBlock_Phoenix_MKDS-1,5-2-5.08_1x02_P5.08mm_Horizont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
R1, R3, R5, R7: 56k; R_0805_2012Metric_Pad1.20x1.40mm_HandSolder
R2, R4, R6, R8: 100k; R_0805_2012Metric_Pad1.20x1.40mm_HandSolder
U1, U2, U3, U4: ACS758xCB-200B-PFF; Allegro_CB_PFF

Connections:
+5V_FL: C2.2, J3.3, U2.1 (VCC)
+5V_FR: C1.2, J1.3, U1.1 (VCC)
+5V_RL: C6.2, J9.3, U4.1 (VCC)
+5V_RR: C5.2, J7.3, U3.1 (VCC)
GND: C1.1, C2.1, C5.1, C6.1, J1.2, J3.2, J7.2, J9.2, R2.2, R4.2, R6.2, R8.2, U1.2 (GND), U2.2 (GND), U3.2 (GND), U4.2 (GND)
unnamed: J1.1, R1.2, R2.1
unnamed: J2.1 (V+), U1.5 (IP-)
unnamed: J3.1, R3.2, R4.1
unnamed: J4.1 (V+), U2.5 (IP-)
unnamed: J7.1, R5.2, R6.1
unnamed: J8.1 (V+), U3.5 (IP-)
unnamed: J9.1, R7.2, R8.1
unnamed: J10.1 (V+), U4.5 (IP-)
unnamed: R1.1, U1.3 (VIOUT)
unnamed: R3.1, U2.3 (VIOUT)
unnamed: R5.1, U3.3 (VIOUT)
unnamed: R7.1, U4.3 (VIOUT)
VBAT+: C3.1, D1.2 (A), J5.1 (V+), U1.4 (IP+), U2.4 (IP+), U3.4 (IP+), U4.4 (IP+)
VBAT-: C3.2, C4.2, J2.2 (V-), J4.2 (V-), J5.2 (V-), J6.1, J8.2 (V-), J10.2 (V-)
VTMDC: C4.1, D1.1 (K), J6.2

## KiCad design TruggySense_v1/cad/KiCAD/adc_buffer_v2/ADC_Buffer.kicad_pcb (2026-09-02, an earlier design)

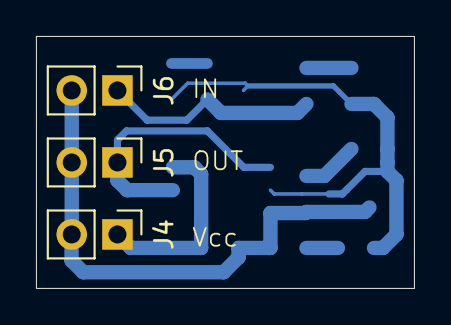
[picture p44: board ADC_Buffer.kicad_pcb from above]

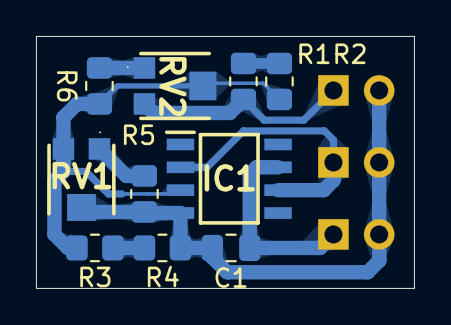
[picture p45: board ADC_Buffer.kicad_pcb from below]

Board: 2 copper layers, 21.0 x 14.0 mm, 13 parts (10 on the bottom side), 9 nets.

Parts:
C1: 10µ; C_0805_2012Metric_Pad1.18x1.45mm_HandSolder
IC1: OPA350UA_2K5; SOIC127P600X175-8N
J4, J5, J6: Conn_01x02; PinHeader_1x02_P2.54mm_Vertical
R1, R2, R3, R4, R5, R6: R; R_0805_2012Metric_Pad1.20x1.40mm_HandSolder
RV1, RV2: R; TC33X2503E

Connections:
GND: C1.2, IC1.4 (V-), J4.2, J5.2, J6.2, R4.1, R5.2, RV1.2
unnamed: IC1.3 (+IN), R2.2, R3.2, R6.2, RV1.3, RV2.2
unnamed: IC1.2 (-IN), IC1.6 (OUTPUT), J5.1
unnamed: J6.1, R1.1, RV2.3
unnamed: R1.2, R2.1
unnamed: R3.1, R4.2
unnamed: R5.1, RV1.1
unnamed: R6.1, RV2.1
VCC: C1.1, IC1.7 (V+), J4.1

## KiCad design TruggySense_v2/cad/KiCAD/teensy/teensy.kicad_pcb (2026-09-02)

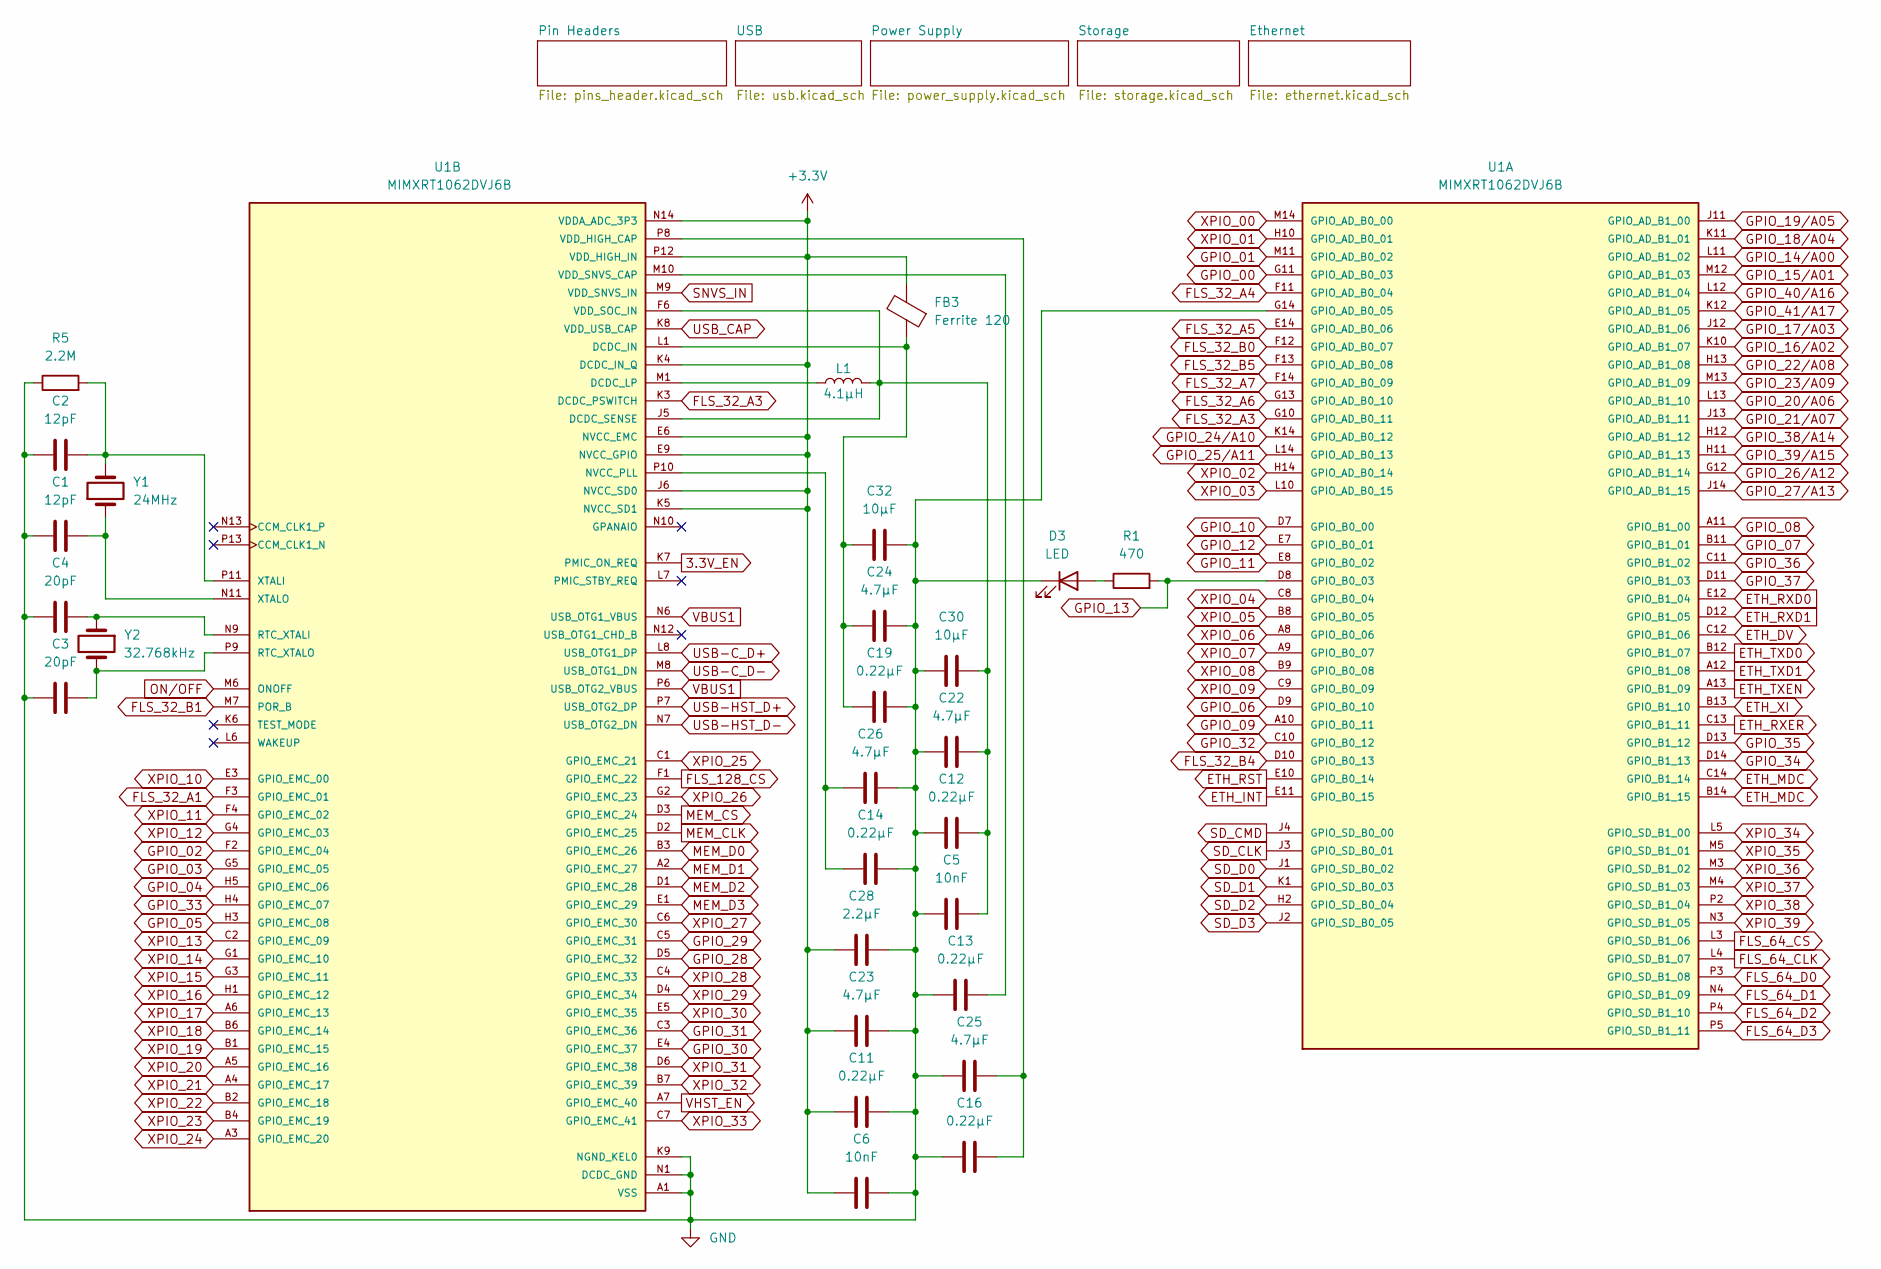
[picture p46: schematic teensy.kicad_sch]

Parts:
C1, C2: 12pF; C_0402_1005Metric
C3, C4: 20pF; C_0402_1005Metric
C5, C6: 10nF; C_0402_1005Metric
C11, C12, C13, C14, C16, C19: 0.22µF; C_0402_1005Metric
C22, C23, C24, C25, C26: 4.7µF; C_0603_1608Metric
C28: 2.2µF; C_0603_1608Metric
C30, C32: 10µF; C_0603_1608Metric
D3: LED; LED_0603_1608Metric
FB3: Ferrite 120; L_0603_1608Metric
L1: 4.1µH; L_0603_1608Metric
R1: 470; R_0402_1005Metric
R5: 2.2M; R_0603_1608Metric
U1: MIMXRT1062DVJ6B; BGA196C80P14X14_1200X1200X152N; PARTREV 3
Y1: 24MHz; Crystal_SMD_0603-2Pin_6.0x3.5mm
Y2: 32.768kHz; Crystal_SMD_0603-2Pin_6.0x3.5mm

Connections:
3.3V_EN: U1.K7 (PMIC_ON_REQ); also elsewhere on the board
+3.3V: C6.1, C11.1, C23.1, C28.1, FB3.2, U1.E6 (NVCC_EMC), U1.E9 (NVCC_GPIO), U1.F5 (NVCC_EMC), U1.F10 (NVCC_GPIO), U1.J6 (NVCC_SD0), U1.J10 (NVCC_GPIO), U1.K4 (DCDC_IN_Q), U1.K5 (NVCC_SD1), U1.N14 (VDDA_ADC_3P3), U1.P12 (VDD_HIGH_IN); also elsewhere on the board
DCDC_IN: C19.1, C24.1, C32.1, FB3.1, U1.L1 (DCDC_IN), U1.L2 (DCDC_IN)
DCDC_LP: L1.1, U1.M1 (DCDC_LP), U1.M2 (DCDC_LP)
ETH_DV: U1.C12 (GPIO_B1_06); also elsewhere on the board
ETH_INT: U1.E11 (GPIO_B0_15); also elsewhere on the board
ETH_MDC: U1.B14 (GPIO_B1_15), U1.C14 (GPIO_B1_14); also elsewhere on the board
ETH_RST: U1.E10 (GPIO_B0_14); also elsewhere on the board
ETH_RXD0: U1.E12 (GPIO_B1_04); also elsewhere on the board
ETH_RXD1: U1.D12 (GPIO_B1_05); also elsewhere on the board
ETH_RXER: U1.C13 (GPIO_B1_11); also elsewhere on the board
ETH_TXD0: U1.B12 (GPIO_B1_07); also elsewhere on the board
ETH_TXD1: U1.A12 (GPIO_B1_08); also elsewhere on the board
ETH_TXEN: U1.A13 (GPIO_B1_09); also elsewhere on the board
ETH_XI: U1.B13 (GPIO_B1_10); also elsewhere on the board
FLS_32_A1: U1.F3 (GPIO_EMC_01); also elsewhere on the board
FLS_32_A3: U1.G10 (GPIO_AD_B0_11), U1.K3 (DCDC_PSWITCH); also elsewhere on the board
FLS_32_A4: U1.F11 (GPIO_AD_B0_04); also elsewhere on the board
FLS_32_A5: U1.E14 (GPIO_AD_B0_06); also elsewhere on the board
FLS_32_A6: U1.G13 (GPIO_AD_B0_10); also elsewhere on the board
FLS_32_A7: U1.F14 (GPIO_AD_B0_09); also elsewhere on the board
FLS_32_B0: U1.F12 (GPIO_AD_B0_07); also elsewhere on the board
FLS_32_B1: U1.M7 (POR_B); also elsewhere on the board
FLS_32_B4: U1.D10 (GPIO_B0_13); also elsewhere on the board
FLS_32_B5: U1.F13 (GPIO_AD_B0_08); also elsewhere on the board
FLS_64_CLK: U1.L4 (GPIO_SD_B1_07); also elsewhere on the board
FLS_64_CS: U1.L3 (GPIO_SD_B1_06); also elsewhere on the board
FLS_64_D0: U1.P3 (GPIO_SD_B1_08); also elsewhere on the board
FLS_64_D1: U1.N4 (GPIO_SD_B1_09); also elsewhere on the board
FLS_64_D2: U1.P4 (GPIO_SD_B1_10); also elsewhere on the board
FLS_64_D3: U1.P5 (GPIO_SD_B1_11); also elsewhere on the board
FLS_128_CS: U1.F1 (GPIO_EMC_22); also elsewhere on the board
GND: C1.1, C2.1, C3.1, C4.1, C5.1, C6.2, C11.2, C12.1, C13.1, C14.2, C16.1, C19.2, C22.1, C23.2, C24.2, C25.1, C26.2, C28.2, C30.1, C32.2, D3.1 (K), R5.1, U1.A1 (VSS), U1.A14 (VSS), U1.B5 (VSS), U1.B10 (VSS), U1.E2 (VSS), U1.E13 (VSS), U1.G7 (VSS), U1.G8 (VSS), U1.G14 (GPIO_AD_B0_05), U1.H7 (VSS), U1.H8 (VSS), U1.J7 (VSS), U1.J8 (VSS), U1.K2 (VSS), U1.K9 (NGND_KEL0), U1.K13 (VSS), U1.L9 (VSS), U1.N1 (DCDC_GND), U1.N2 (DCDC_GND), U1.N5 (VSS), U1.N8 (VSS), U1.P1 (VSS), U1.P14 (VSS); also elsewhere on the board
GPIO_00: U1.G11 (GPIO_AD_B0_03); also elsewhere on the board
GPIO_01: U1.M11 (GPIO_AD_B0_02); also elsewhere on the board
GPIO_02: U1.F2 (GPIO_EMC_04); also elsewhere on the board
GPIO_03: U1.G5 (GPIO_EMC_05); also elsewhere on the board
GPIO_04: U1.H5 (GPIO_EMC_06); also elsewhere on the board
GPIO_05: U1.H3 (GPIO_EMC_08); also elsewhere on the board
GPIO_06: U1.D9 (GPIO_B0_10); also elsewhere on the board
GPIO_07: U1.B11 (GPIO_B1_01); also elsewhere on the board
GPIO_08: U1.A11 (GPIO_B1_00); also elsewhere on the board
GPIO_09: U1.A10 (GPIO_B0_11); also elsewhere on the board
GPIO_10: U1.D7 (GPIO_B0_00); also elsewhere on the board
GPIO_11: U1.E8 (GPIO_B0_02); also elsewhere on the board
GPIO_12: U1.E7 (GPIO_B0_01); also elsewhere on the board
GPIO_13: R1.2, U1.D8 (GPIO_B0_03); also elsewhere on the board
GPIO_14/A00: U1.L11 (GPIO_AD_B1_02); also elsewhere on the board
GPIO_15/A01: U1.M12 (GPIO_AD_B1_03); also elsewhere on the board
GPIO_16/A02: U1.K10 (GPIO_AD_B1_07); also elsewhere on the board
GPIO_17/A03: U1.J12 (GPIO_AD_B1_06); also elsewhere on the board
GPIO_18/A04: U1.K11 (GPIO_AD_B1_01); also elsewhere on the board
GPIO_19/A05: U1.J11 (GPIO_AD_B1_00); also elsewhere on the board
GPIO_20/A06: U1.L13 (GPIO_AD_B1_10); also elsewhere on the board
GPIO_21/A07: U1.J13 (GPIO_AD_B1_11); also elsewhere on the board
GPIO_22/A08: U1.H13 (GPIO_AD_B1_08); also elsewhere on the board
GPIO_23/A09: U1.M13 (GPIO_AD_B1_09); also elsewhere on the board
GPIO_24/A10: U1.K14 (GPIO_AD_B0_12); also elsewhere on the board
GPIO_25/A11: U1.L14 (GPIO_AD_B0_13); also elsewhere on the board
GPIO_26/A12: U1.G12 (GPIO_AD_B1_14); also elsewhere on the board
GPIO_27/A13: U1.J14 (GPIO_AD_B1_15); also elsewhere on the board
GPIO_28: U1.D5 (GPIO_EMC_32); also elsewhere on the board
GPIO_29: U1.C5 (GPIO_EMC_31); also elsewhere on the board
GPIO_30: U1.E4 (GPIO_EMC_37); also elsewhere on the board
GPIO_31: U1.C3 (GPIO_EMC_36); also elsewhere on the board
GPIO_32: U1.C10 (GPIO_B0_12); also elsewhere on the board
GPIO_33: U1.H4 (GPIO_EMC_07); also elsewhere on the board
GPIO_34: U1.D14 (GPIO_B1_13); also elsewhere on the board
GPIO_35: U1.D13 (GPIO_B1_12); also elsewhere on the board
GPIO_36: U1.C11 (GPIO_B1_02); also elsewhere on the board
GPIO_37: U1.D11 (GPIO_B1_03); also elsewhere on the board
GPIO_38/A14: U1.H12 (GPIO_AD_B1_12); also elsewhere on the board
GPIO_39/A15: U1.H11 (GPIO_AD_B1_13); also elsewhere on the board
GPIO_40/A16: U1.L12 (GPIO_AD_B1_04); also elsewhere on the board
GPIO_41/A17: U1.K12 (GPIO_AD_B1_05); also elsewhere on the board
MEM_CLK: U1.D2 (GPIO_EMC_25); also elsewhere on the board
MEM_CS: U1.D3 (GPIO_EMC_24); also elsewhere on the board
MEM_D0: U1.B3 (GPIO_EMC_26); also elsewhere on the board
MEM_D1: U1.A2 (GPIO_EMC_27); also elsewhere on the board
MEM_D2: U1.D1 (GPIO_EMC_28); also elsewhere on the board
MEM_D3: U1.E1 (GPIO_EMC_29); also elsewhere on the board
unnamed: D3.2 (A), R1.1
unnamed: C14.1, C26.1, U1.P10 (NVCC_PLL)
unnamed: C4.2, U1.N9 (RTC_XTALI), Y2.1
unnamed: C3.2, U1.P9 (RTC_XTALO), Y2.2
unnamed: C16.2, C25.2, U1.P8 (VDD_HIGH_CAP)
unnamed: C13.2, U1.M10 (VDD_SNVS_CAP)
unnamed: C2.2, R5.2, U1.P11 (XTALI), Y1.2
unnamed: C1.2, U1.N11 (XTALO), Y1.1
ON/OFF: U1.M6 (ONOFF); also elsewhere on the board
SD_CLK: U1.J3 (GPIO_SD_B0_01); also elsewhere on the board
SD_CMD: U1.J4 (GPIO_SD_B0_00); also elsewhere on the board
SD_D0: U1.J1 (GPIO_SD_B0_02); also elsewhere on the board
SD_D1: U1.K1 (GPIO_SD_B0_03); also elsewhere on the board
SD_D2: U1.H2 (GPIO_SD_B0_04); also elsewhere on the board
SD_D3: U1.J2 (GPIO_SD_B0_05); also elsewhere on the board
SNVS_IN: U1.M9 (VDD_SNVS_IN); also elsewhere on the board
USB-C_D+: U1.L8 (USB_OTG1_DP); also elsewhere on the board
USB-C_D-: U1.M8 (USB_OTG1_DN); also elsewhere on the board
USB-HST_D+: U1.P7 (USB_OTG2_DP); also elsewhere on the board
USB-HST_D-: U1.N7 (USB_OTG2_DN); also elsewhere on the board
USB_CAP: U1.K8 (VDD_USB_CAP); also elsewhere on the board
VBUS1: U1.N6 (USB_OTG1_VBUS), U1.P6 (USB_OTG2_VBUS); also elsewhere on the board
VDD_SOC_IN: C5.2, C12.2, C22.2, C30.2, L1.2, U1.F6 (VDD_SOC_IN), U1.F7 (VDD_SOC_IN), U1.F8 (VDD_SOC_IN), U1.F9 (VDD_SOC_IN), U1.G6 (VDD_SOC_IN), U1.G9 (VDD_SOC_IN), U1.H6 (VDD_SOC_IN), U1.H9 (VDD_SOC_IN), U1.J5 (DCDC_SENSE), U1.J9 (VDD_SOC_IN)
VHST_EN: U1.A7 (GPIO_EMC_40); also elsewhere on the board
XPIO_00: U1.M14 (GPIO_AD_B0_00); also elsewhere on the board
XPIO_01: U1.H10 (GPIO_AD_B0_01); also elsewhere on the board
XPIO_02: U1.H14 (GPIO_AD_B0_14); also elsewhere on the board
XPIO_03: U1.L10 (GPIO_AD_B0_15); also elsewhere on the board
XPIO_04: U1.C8 (GPIO_B0_04); also elsewhere on the board
XPIO_05: U1.B8 (GPIO_B0_05); also elsewhere on the board
XPIO_06: U1.A8 (GPIO_B0_06); also elsewhere on the board
XPIO_07: U1.A9 (GPIO_B0_07); also elsewhere on the board
XPIO_08: U1.B9 (GPIO_B0_08); also elsewhere on the board
XPIO_09: U1.C9 (GPIO_B0_09); also elsewhere on the board
XPIO_10: U1.E3 (GPIO_EMC_00); also elsewhere on the board
XPIO_11: U1.F4 (GPIO_EMC_02); also elsewhere on the board
XPIO_12: U1.G4 (GPIO_EMC_03); also elsewhere on the board
XPIO_13: U1.C2 (GPIO_EMC_09); also elsewhere on the board
XPIO_14: U1.G1 (GPIO_EMC_10); also elsewhere on the board
XPIO_15: U1.G3 (GPIO_EMC_11); also elsewhere on the board
XPIO_16: U1.H1 (GPIO_EMC_12); also elsewhere on the board
XPIO_17: U1.A6 (GPIO_EMC_13); also elsewhere on the board
XPIO_18: U1.B6 (GPIO_EMC_14); also elsewhere on the board
XPIO_19: U1.B1 (GPIO_EMC_15); also elsewhere on the board
XPIO_20: U1.A5 (GPIO_EMC_16); also elsewhere on the board
XPIO_21: U1.A4 (GPIO_EMC_17); also elsewhere on the board
XPIO_22: U1.B2 (GPIO_EMC_18); also elsewhere on the board
XPIO_23: U1.B4 (GPIO_EMC_19); also elsewhere on the board
XPIO_24: U1.A3 (GPIO_EMC_20); also elsewhere on the board
XPIO_25: U1.C1 (GPIO_EMC_21); also elsewhere on the board
XPIO_26: U1.G2 (GPIO_EMC_23); also elsewhere on the board
XPIO_27: U1.C6 (GPIO_EMC_30); also elsewhere on the board
XPIO_28: U1.C4 (GPIO_EMC_33); also elsewhere on the board
XPIO_29: U1.D4 (GPIO_EMC_34); also elsewhere on the board
XPIO_30: U1.E5 (GPIO_EMC_35); also elsewhere on the board
XPIO_31: U1.D6 (GPIO_EMC_38); also elsewhere on the board
XPIO_32: U1.B7 (GPIO_EMC_39); also elsewhere on the board
XPIO_33: U1.C7 (GPIO_EMC_41); also elsewhere on the board
XPIO_34: U1.L5 (GPIO_SD_B1_00); also elsewhere on the board
XPIO_35: U1.M5 (GPIO_SD_B1_01); also elsewhere on the board
XPIO_36: U1.M3 (GPIO_SD_B1_02); also elsewhere on the board
XPIO_37: U1.M4 (GPIO_SD_B1_03); also elsewhere on the board
XPIO_38: U1.P2 (GPIO_SD_B1_04); also elsewhere on the board
XPIO_39: U1.N3 (GPIO_SD_B1_05); also elsewhere on the board

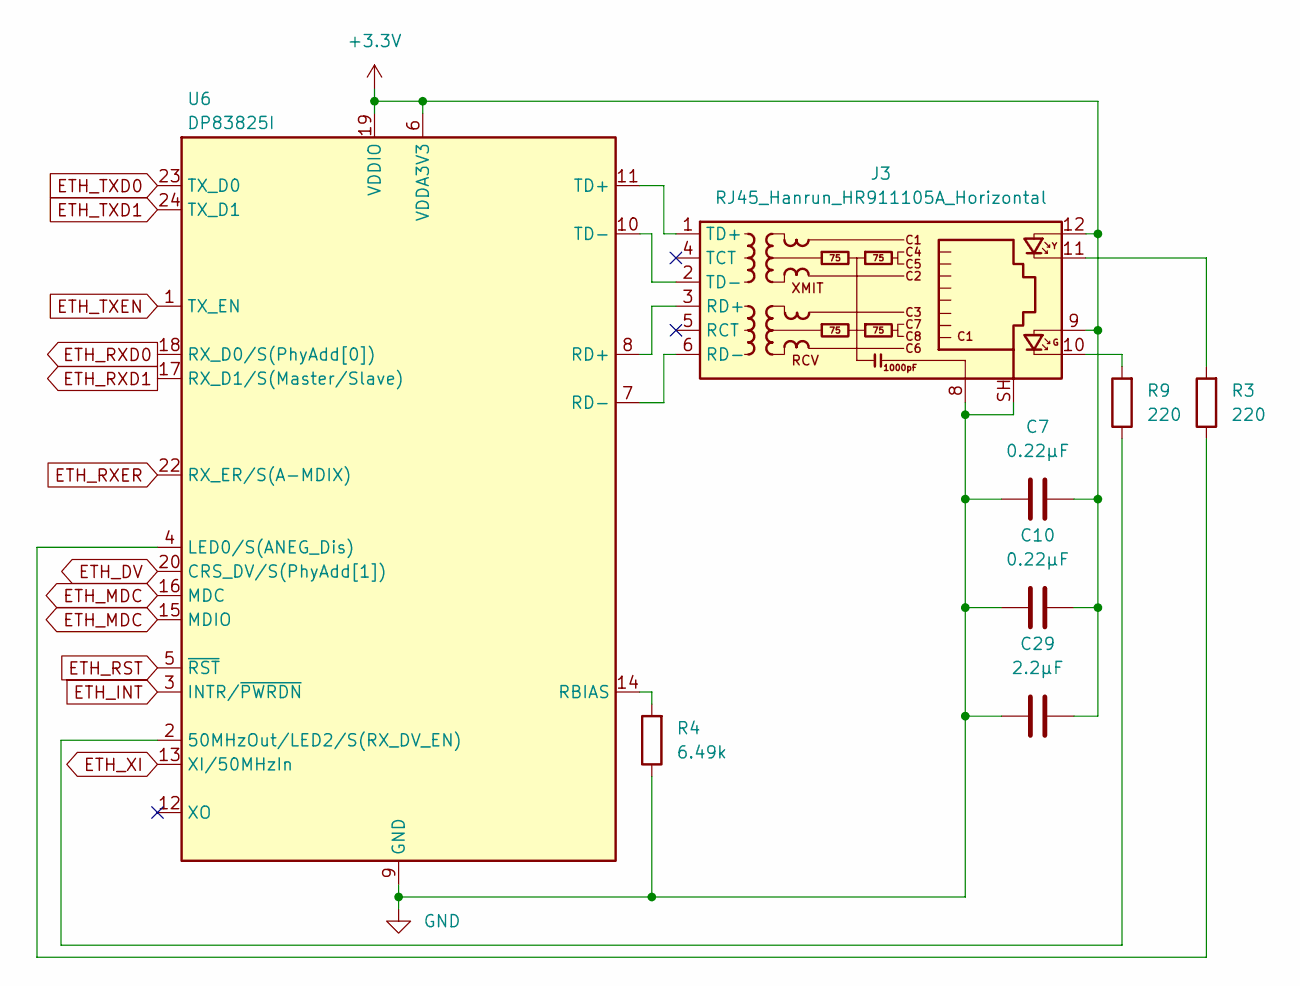
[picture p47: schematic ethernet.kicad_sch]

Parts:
C7, C10: 0.22µF; C_0402_1005Metric
C29: 2.2µF; C_0603_1608Metric
J3: RJ45_Hanrun_HR911105A_Horizontal
R3, R9: 220; R_0402_1005Metric
R4: 6.49k; R_0402_1005Metric
U6: DP83825I; Texas_RMQ0024A_WQFN-24-1EP_3x3mm_P0.4mm_EP1.9x1.9mm

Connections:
+3.3V: C7.2, C10.2, C29.2, J3.9, J3.12, U6.6 (VDDA3V3), U6.19 (VDDIO); also elsewhere on the board
ETH_DV: U6.20 (CRS_DV/S(PhyAdd[1])); also elsewhere on the board
ETH_INT: U6.3 (INTR/~PWRDN); also elsewhere on the board
ETH_MDC: U6.15 (MDIO), U6.16 (MDC); also elsewhere on the board
ETH_RST: U6.5 (~RST); also elsewhere on the board
ETH_RXD0: U6.18 (RX_D0/S(PhyAdd[0])); also elsewhere on the board
ETH_RXD1: U6.17 (RX_D1/S(Master/Slave)); also elsewhere on the board
ETH_RXER: U6.22 (RX_ER/S(A-MDIX)); also elsewhere on the board
ETH_TXD0: U6.23 (TX_D0); also elsewhere on the board
ETH_TXD1: U6.24 (TX_D1); also elsewhere on the board
ETH_TXEN: U6.1 (TX_EN); also elsewhere on the board
ETH_XI: U6.13 (XI/50MHzIn); also elsewhere on the board
GND: C7.1, C10.1, C29.1, J3.8, J3.SH, R4.1, U6.9 (GND), U6.21 (GND), U6.25 (GND); also elsewhere on the board
unnamed: J3.10, R9.2
unnamed: J3.11, R3.2
unnamed: J3.3 (RD+), U6.8 (RD+)
unnamed: J3.6 (RD-), U6.7 (RD-)
unnamed: J3.1 (TD+), U6.11 (TD+)
unnamed: J3.2 (TD-), U6.10 (TD-)
unnamed: R9.1, U6.2 (50MHzOut/LED2/S(RX_DV_EN))
unnamed: R3.1, U6.4 (LED0/S(ANEG_Dis))
unnamed: R4.2, U6.14 (RBIAS)

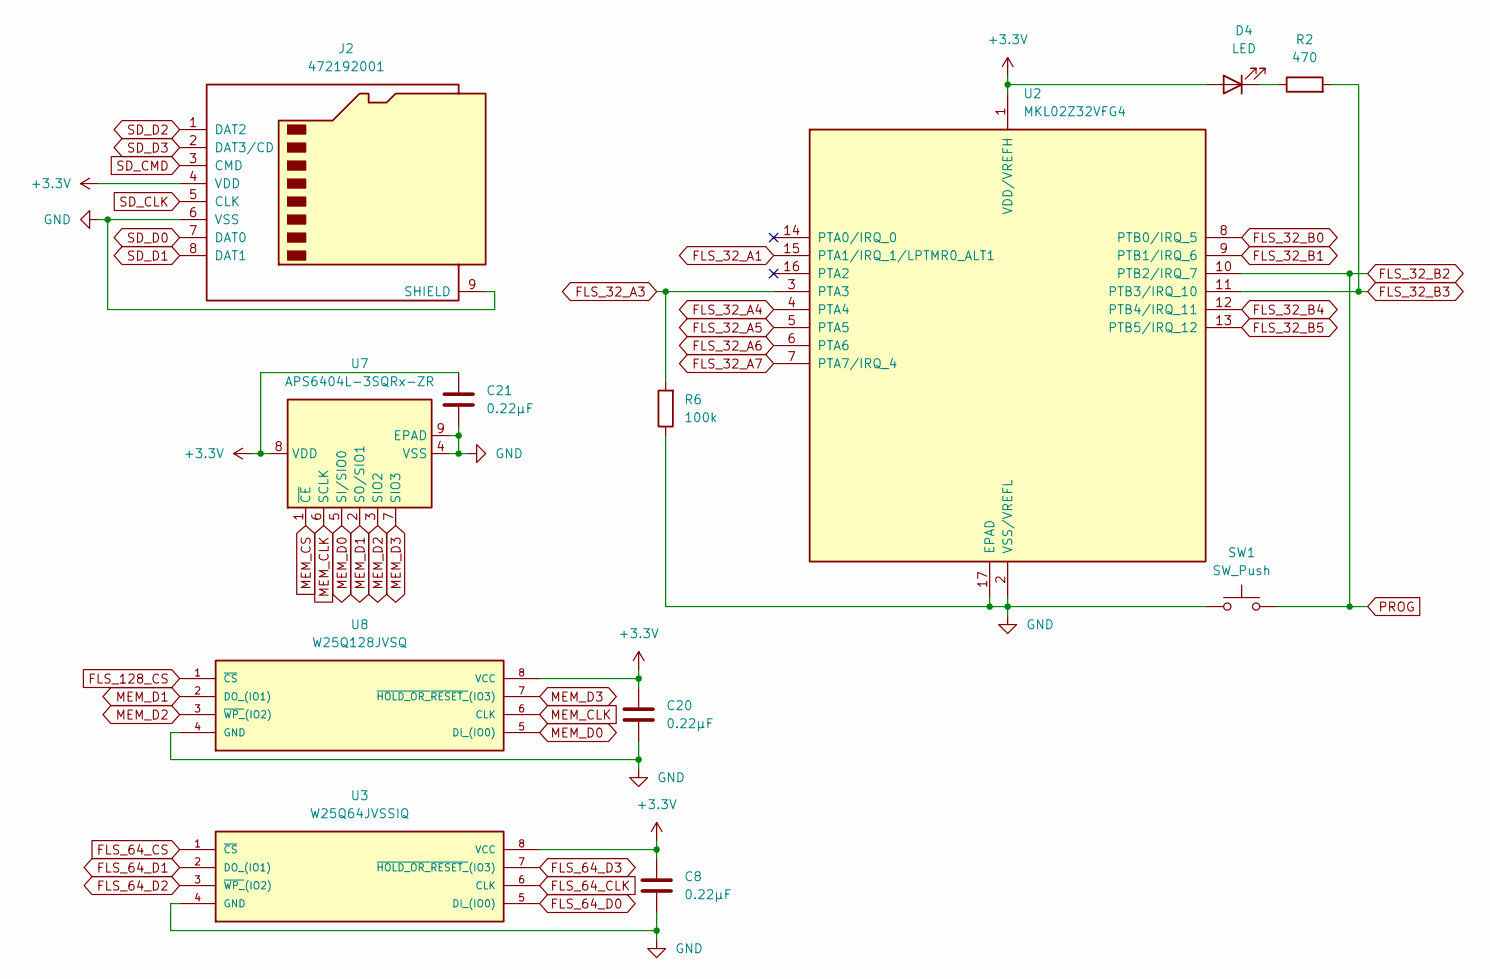
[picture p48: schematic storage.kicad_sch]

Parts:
C8, C20, C21: 0.22µF; C_0402_1005Metric
D4: LED; LED_0603_1608Metric
J2: 472192001; microSD_HC_Molex_47219-2001
R2: 470; R_0402_1005Metric
R6: 100k; R_0603_1608Metric
SW1: SW_Push; SW_SPST_EVQP2_MiddlePushTravel_H2.5mm
U2: MKL02Z32VFG4; QFN-16-1EP_3x3mm_P0.5mm_EP1.9x1.9mm
U3: W25Q64JVSSIQ; SOIC127P790X216-8N; MANUFACTURER_PART_NUMBER W25Q64JVSSIQ
U7: APS6404L-3SQRx-ZR; Winbond_USON-8-1EP_3x2mm_P0.5mm_EP0.2x1.6mm
U8: W25Q128JVSQ; SOIC127P790X216-8N; MANUFACTURER_PART_NUMBER W25Q128JVSQ

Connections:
+3.3V: C8.1, C20.1, C21.1, D4.2 (A), J2.4 (VDD), U2.1 (VDD/VREFH), U3.8 (VCC), U7.8 (VDD), U8.8 (VCC); also elsewhere on the board
FLS_32_A1: U2.15 (PTA1/IRQ_1/LPTMR0_ALT1); also elsewhere on the board
FLS_32_A3: R6.2, U2.3 (PTA3); also elsewhere on the board
FLS_32_A4: U2.4 (PTA4); also elsewhere on the board
FLS_32_A5: U2.5 (PTA5); also elsewhere on the board
FLS_32_A6: U2.6 (PTA6); also elsewhere on the board
FLS_32_A7: U2.7 (PTA7/IRQ_4); also elsewhere on the board
FLS_32_B0: U2.8 (PTB0/IRQ_5); also elsewhere on the board
FLS_32_B1: U2.9 (PTB1/IRQ_6); also elsewhere on the board
FLS_32_B2: SW1.2, U2.10 (PTB2/IRQ_7); also elsewhere on the board
FLS_32_B3: R2.2, U2.11 (PTB3/IRQ_10)
FLS_32_B4: U2.12 (PTB4/IRQ_11); also elsewhere on the board
FLS_32_B5: U2.13 (PTB5/IRQ_12); also elsewhere on the board
FLS_64_CLK: U3.6 (CLK); also elsewhere on the board
FLS_64_CS: U3.1 (~CS); also elsewhere on the board
FLS_64_D0: U3.5 (DI_(IO0)); also elsewhere on the board
FLS_64_D1: U3.2 (DO_(IO1)); also elsewhere on the board
FLS_64_D2: U3.3 (~WP_(IO2)); also elsewhere on the board
FLS_64_D3: U3.7 (~HOLD_OR_~RESET_(IO3)); also elsewhere on the board
FLS_128_CS: U8.1 (~CS); also elsewhere on the board
GND: C8.2, C20.2, C21.2, J2.6 (VSS), J2.9 (SHIELD), R6.1, SW1.1, U2.2 (VSS/VREFL), U2.17 (EPAD), U3.4 (GND), U7.4 (VSS), U7.9 (EPAD), U8.4 (GND); also elsewhere on the board
MEM_CLK: U7.6 (SCLK), U8.6 (CLK); also elsewhere on the board
MEM_CS: U7.1 (~CE); also elsewhere on the board
MEM_D0: U7.5 (SI/SIO0), U8.5 (DI_(IO0)); also elsewhere on the board
MEM_D1: U7.2 (SO/SIO1), U8.2 (DO_(IO1)); also elsewhere on the board
MEM_D2: U7.3 (SIO2), U8.3 (~WP_(IO2)); also elsewhere on the board
MEM_D3: U7.7 (SIO3), U8.7 (~HOLD_OR_~RESET_(IO3)); also elsewhere on the board
unnamed: D4.1 (K), R2.1
SD_CLK: J2.5 (CLK); also elsewhere on the board
SD_CMD: J2.3 (CMD); also elsewhere on the board
SD_D0: J2.7 (DAT0); also elsewhere on the board
SD_D1: J2.8 (DAT1); also elsewhere on the board
SD_D2: J2.1 (DAT2); also elsewhere on the board
SD_D3: J2.2 (DAT3/CD); also elsewhere on the board

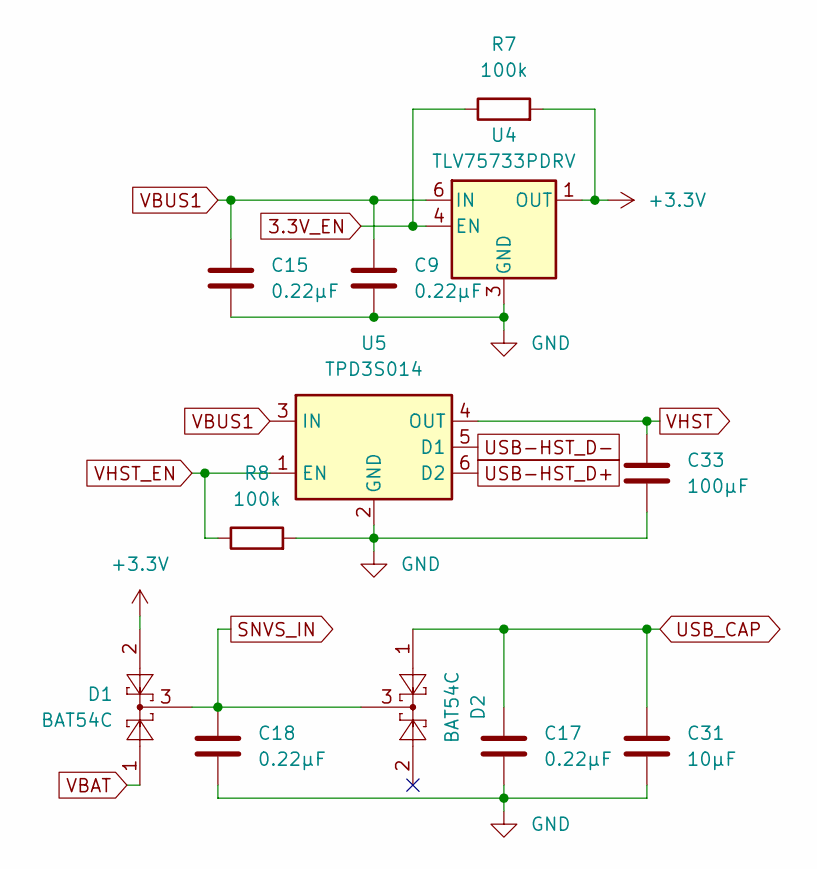
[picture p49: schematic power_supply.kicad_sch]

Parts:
C9, C15, C17, C18: 0.22µF; C_0402_1005Metric
C31: 10µF; C_0603_1608Metric
C33: 100µF; C_0603_1608Metric
D1, D2: BAT54C; SOT-23
R7, R8: 100k; R_0603_1608Metric
U4: TLV75733PDRV; WSON-6-1EP_2x2mm_P0.65mm_EP1x1.6mm
U5: TPD3S014; SOT-23-6

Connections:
3.3V_EN: R7.1, U4.4 (EN); also elsewhere on the board
+3.3V: D1.2, R7.2, U4.1 (OUT); also elsewhere on the board
GND: C9.2, C15.2, C17.1, C18.2, C31.1, C33.2, R8.2, U4.3 (GND), U4.7 (GND), U5.2 (GND); also elsewhere on the board
SNVS_IN: C18.1, D1.3, D2.3; also elsewhere on the board
USB-HST_D+: U5.6 (D2); also elsewhere on the board
USB-HST_D-: U5.5 (D1); also elsewhere on the board
USB_CAP: C17.2, C31.2, D2.1; also elsewhere on the board
VBAT: D1.1; also elsewhere on the board
VBUS1: C9.1, C15.1, U4.6 (IN), U5.3 (IN); also elsewhere on the board
VHST: C33.1, U5.4 (OUT); also elsewhere on the board
VHST_EN: R8.1, U5.1 (EN); also elsewhere on the board

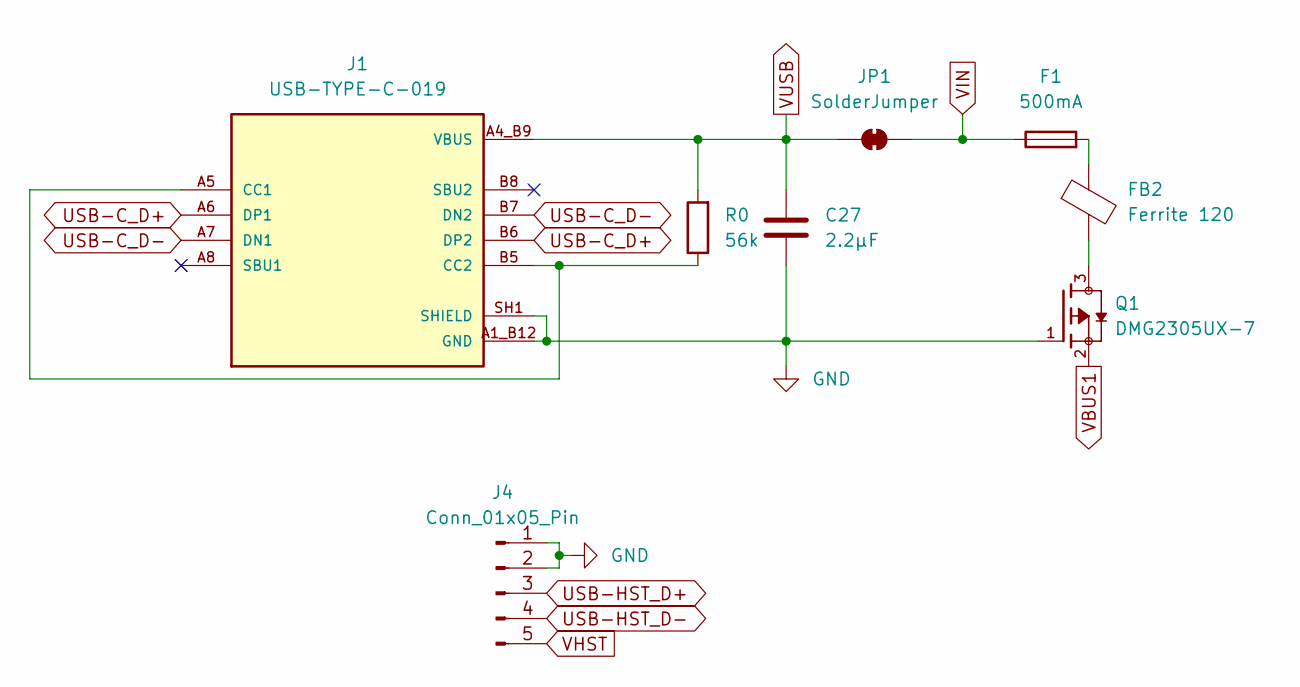
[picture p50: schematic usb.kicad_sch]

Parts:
C27: 2.2µF; C_0603_1608Metric
F1: 500mA; Fuse_0603_1608Metric
FB2: Ferrite 120; L_0603_1608Metric
J1: USB-TYPE-C-019; AMPHENOL_10155435-00031LF; PARTREV C
J4: Conn_01x05_Pin; PinHeader_1x05_P2.54mm_Vertical
JP1: SolderJumper; SolderJumper-2_P1.3mm_Open_TrianglePad1.0x1.5mm
Q1: DMG2305UX-7; SOT91P240X110-3N_DMG2305UX-7; PARTREV 09/2018
R0: 56k; R_0603_1608Metric

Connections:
GND: C27.1, J1.A1_B12 (GND), J1.B1_A12 (GND), J1.SH1 (SHIELD), J1.SH2 (SHIELD), J1.SH3 (SHIELD), J1.SH4 (SHIELD), J4.1, J4.2, Q1.1; also elsewhere on the board
unnamed: F1.2, FB2.1
unnamed: FB2.2, Q1.3
unnamed: J1.A5 (CC1), J1.B5 (CC2), R0.1
USB-C_D+: J1.A6 (DP1), J1.B6 (DP2); also elsewhere on the board
USB-C_D-: J1.A7 (DN1), J1.B7 (DN2); also elsewhere on the board
USB-HST_D+: J4.3; also elsewhere on the board
USB-HST_D-: J4.4; also elsewhere on the board
VBUS1: Q1.2; also elsewhere on the board
VHST: J4.5; also elsewhere on the board
VIN: F1.1, JP1.2 (B); also elsewhere on the board
VUSB: C27.2, J1.A4_B9 (VBUS), J1.B4_A9 (VBUS), JP1.1 (A), R0.2; also elsewhere on the board

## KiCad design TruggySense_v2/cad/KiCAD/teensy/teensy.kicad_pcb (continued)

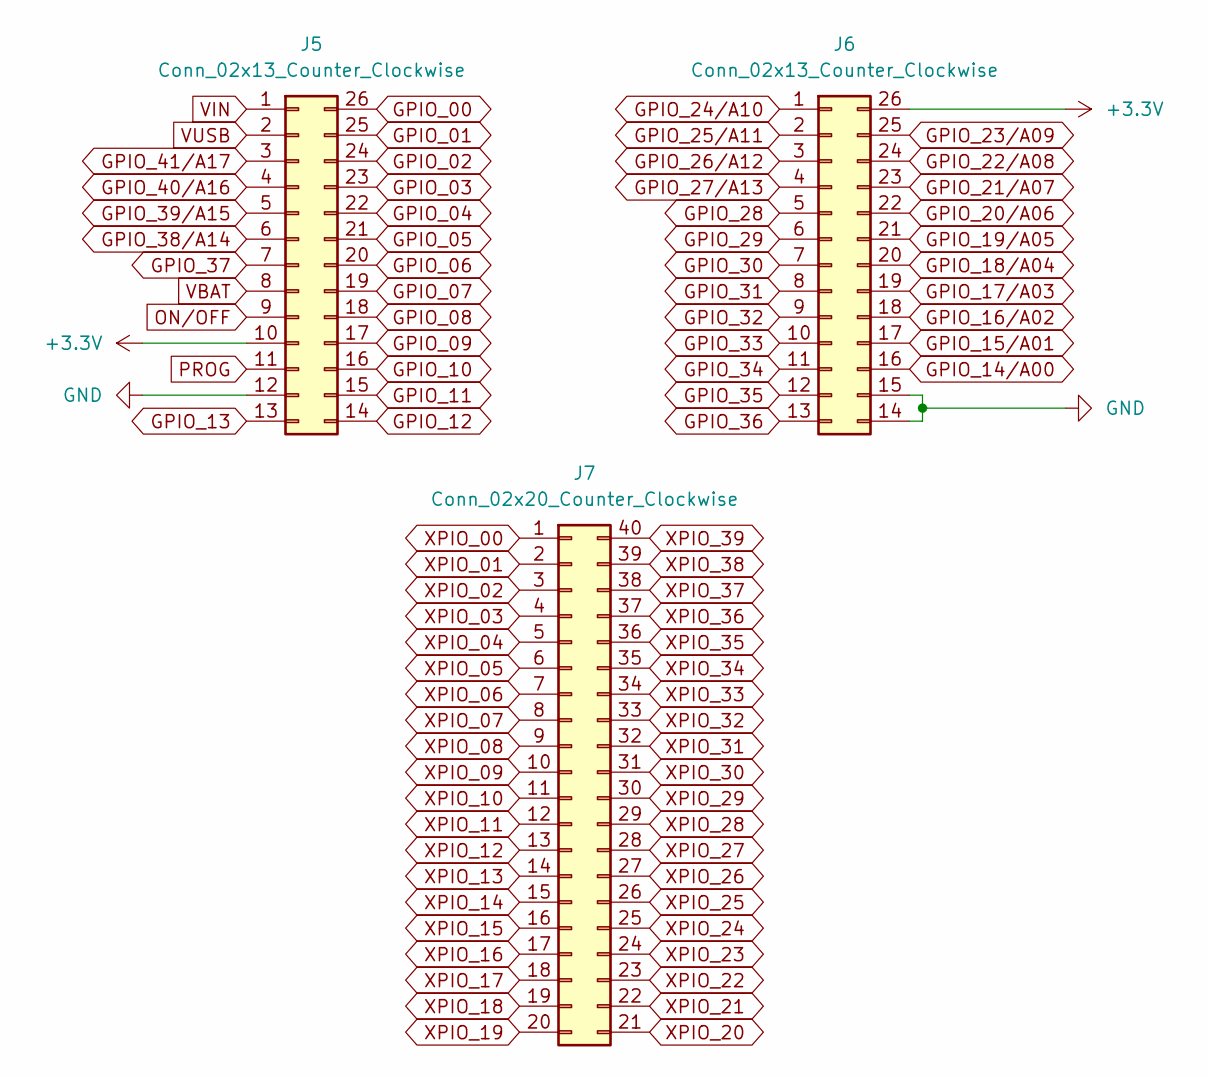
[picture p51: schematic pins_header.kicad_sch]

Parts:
J5, J6: Conn_02x13_Counter_Clockwise; PinSocket_2x13_P2.54mm_Vertical
J7: Conn_02x20_Counter_Clockwise; PinHeader_2x20_P2.54mm_Vertical

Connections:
+3.3V: J5.10, J6.26; also elsewhere on the board
FLS_32_B2: J5.11; also elsewhere on the board
GND: J5.12, J6.14, J6.15; also elsewhere on the board
GPIO_00: J5.26; also elsewhere on the board
GPIO_01: J5.25; also elsewhere on the board
GPIO_02: J5.24; also elsewhere on the board
GPIO_03: J5.23; also elsewhere on the board
GPIO_04: J5.22; also elsewhere on the board
GPIO_05: J5.21; also elsewhere on the board
GPIO_06: J5.20; also elsewhere on the board
GPIO_07: J5.19; also elsewhere on the board
GPIO_08: J5.18; also elsewhere on the board
GPIO_09: J5.17; also elsewhere on the board
GPIO_10: J5.16; also elsewhere on the board
GPIO_11: J5.15; also elsewhere on the board
GPIO_12: J5.14; also elsewhere on the board
GPIO_13: J5.13; also elsewhere on the board
GPIO_14/A00: J6.16; also elsewhere on the board
GPIO_15/A01: J6.17; also elsewhere on the board
GPIO_16/A02: J6.18; also elsewhere on the board
GPIO_17/A03: J6.19; also elsewhere on the board
GPIO_18/A04: J6.20; also elsewhere on the board
GPIO_19/A05: J6.21; also elsewhere on the board
GPIO_20/A06: J6.22; also elsewhere on the board
GPIO_21/A07: J6.23; also elsewhere on the board
GPIO_22/A08: J6.24; also elsewhere on the board
GPIO_23/A09: J6.25; also elsewhere on the board
GPIO_24/A10: J6.1; also elsewhere on the board
GPIO_25/A11: J6.2; also elsewhere on the board
GPIO_26/A12: J6.3; also elsewhere on the board
GPIO_27/A13: J6.4; also elsewhere on the board
GPIO_28: J6.5; also elsewhere on the board
GPIO_29: J6.6; also elsewhere on the board
GPIO_30: J6.7; also elsewhere on the board
GPIO_31: J6.8; also elsewhere on the board
GPIO_32: J6.9; also elsewhere on the board
GPIO_33: J6.10; also elsewhere on the board
GPIO_34: J6.11; also elsewhere on the board
GPIO_35: J6.12; also elsewhere on the board
GPIO_36: J6.13; also elsewhere on the board
GPIO_37: J5.7; also elsewhere on the board
GPIO_38/A14: J5.6; also elsewhere on the board
GPIO_39/A15: J5.5; also elsewhere on the board
GPIO_40/A16: J5.4; also elsewhere on the board
GPIO_41/A17: J5.3; also elsewhere on the board
ON/OFF: J5.9; also elsewhere on the board
VBAT: J5.8; also elsewhere on the board
VIN: J5.1; also elsewhere on the board
VUSB: J5.2; also elsewhere on the board
XPIO_00: J7.1; also elsewhere on the board
XPIO_01: J7.2; also elsewhere on the board
XPIO_02: J7.3; also elsewhere on the board
XPIO_03: J7.4; also elsewhere on the board
XPIO_04: J7.5; also elsewhere on the board
XPIO_05: J7.6; also elsewhere on the board
XPIO_06: J7.7; also elsewhere on the board
XPIO_07: J7.8; also elsewhere on the board
XPIO_08: J7.9; also elsewhere on the board
XPIO_09: J7.10; also elsewhere on the board
XPIO_10: J7.11; also elsewhere on the board
XPIO_11: J7.12; also elsewhere on the board
XPIO_12: J7.13; also elsewhere on the board
XPIO_13: J7.14; also elsewhere on the board
XPIO_14: J7.15; also elsewhere on the board
XPIO_15: J7.16; also elsewhere on the board
XPIO_16: J7.17; also elsewhere on the board
XPIO_17: J7.18; also elsewhere on the board
XPIO_18: J7.19; also elsewhere on the board
XPIO_19: J7.20; also elsewhere on the board
XPIO_20: J7.21; also elsewhere on the board
XPIO_21: J7.22; also elsewhere on the board
XPIO_22: J7.23; also elsewhere on the board
XPIO_23: J7.24; also elsewhere on the board
XPIO_24: J7.25; also elsewhere on the board
XPIO_25: J7.26; also elsewhere on the board
XPIO_26: J7.27; also elsewhere on the board
XPIO_27: J7.28; also elsewhere on the board
XPIO_28: J7.29; also elsewhere on the board
XPIO_29: J7.30; also elsewhere on the board
XPIO_30: J7.31; also elsewhere on the board
XPIO_31: J7.32; also elsewhere on the board
XPIO_32: J7.33; also elsewhere on the board
XPIO_33: J7.34; also elsewhere on the board
XPIO_34: J7.35; also elsewhere on the board
XPIO_35: J7.36; also elsewhere on the board
XPIO_36: J7.37; also elsewhere on the board
XPIO_37: J7.38; also elsewhere on the board
XPIO_38: J7.39; also elsewhere on the board
XPIO_39: J7.40; also elsewhere on the board

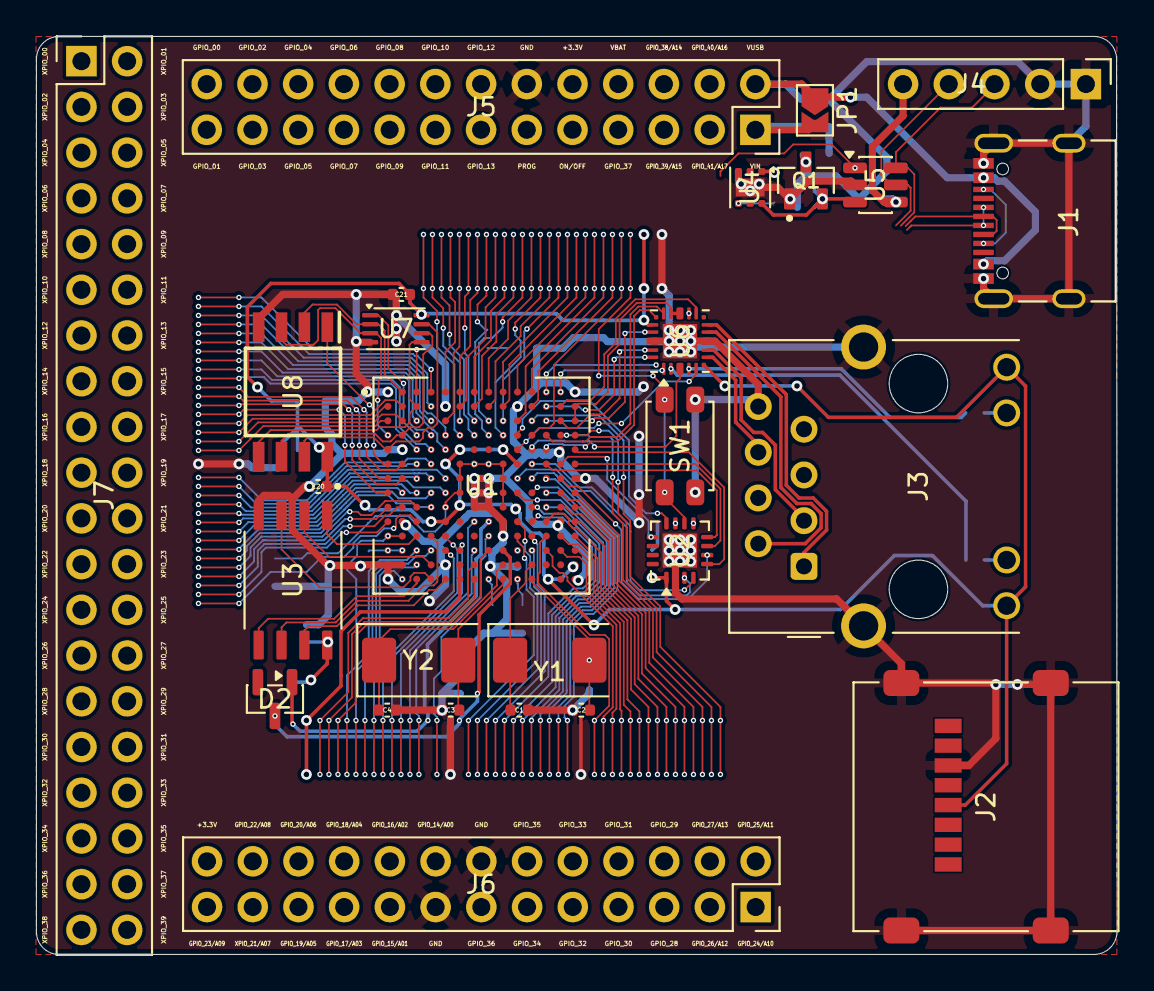
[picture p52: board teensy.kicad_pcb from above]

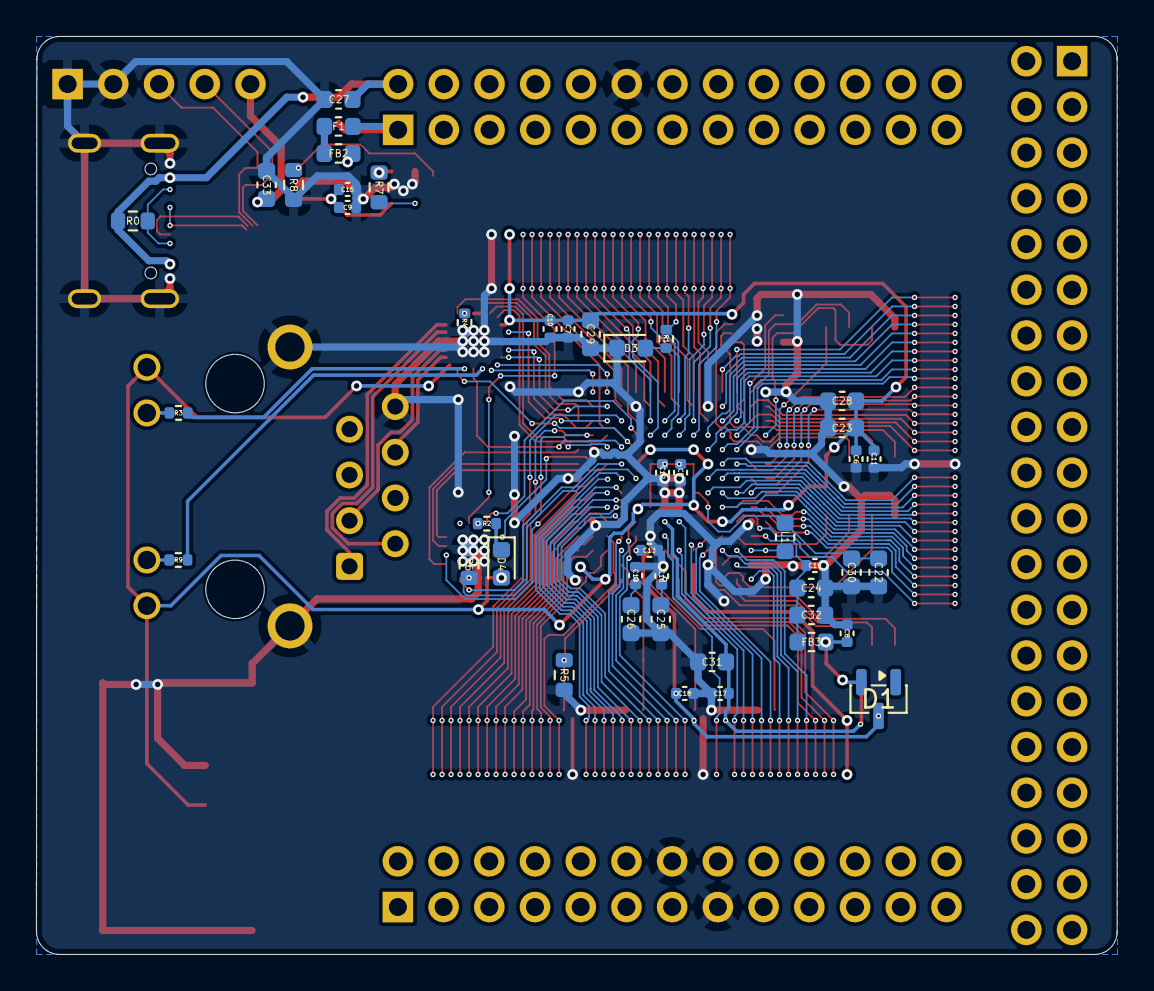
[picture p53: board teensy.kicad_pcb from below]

Board: 2 copper layers, 60.0 x 51.0 mm, 71 parts (44 on the bottom side), 164 nets.

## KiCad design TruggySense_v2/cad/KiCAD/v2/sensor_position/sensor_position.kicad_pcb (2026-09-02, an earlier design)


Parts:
C1: 56pF; C_0805_2012Metric_Pad1.18x1.45mm_HandSolder; MPN GRM1555C1H560JA01D; Digi-Key_PN 490-1288-1-ND
C2, C5: 1.8pF; C_0805_2012Metric_Pad1.18x1.45mm_HandSolder
C3: 15pF; C_0805_2012Metric_Pad1.18x1.45mm_HandSolder
C4: 1µF; C_0805_2012Metric_Pad1.18x1.45mm_HandSolder
C6: 100pF; C_0805_2012Metric_Pad1.18x1.45mm_HandSolder
C7: 100nF; C_0805_2012Metric_Pad1.18x1.45mm_HandSolder
D1: DF2B5M4ASL,L3F; DF2B5M4ASL
J1: GNSS_ANT; SMA_Molex_73251-1153_EdgeMount_Horizontal
J2, J3: IO; PinHeader_1x05_P2.54mm_Vertical
L1: 56nH; L_0805_2012Metric_Pad1.05x1.20mm_HandSolder; MPN 744784156A; Digi-Key_PN 732-6242-1-ND
L2: 4.7nH; L_0805_2012Metric_Pad1.05x1.20mm_HandSolder
R1, R2: 0; R_0805_2012Metric_Pad1.20x1.40mm_HandSolder
R3, R4, R5: 10k; R_0805_2012Metric_Pad1.20x1.40mm_HandSolder
U1: BGA715N7E6327XTSA2; AMP_BGA715N7
U3: TESEO-LIV3F
U4: SF2463H

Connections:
+3V3: C6.2, C7.1, J2.5, R4.1, R5.1, U3.6 (VBATT), U3.7 (VCC_IO), U3.8 (VCC)
ANT_OFF: R3.1, U1.4 (PON), U3.13 (ANT_OFF)
ANT_PPS: J2.2, U3.4 (PPS)
ANT_RST: J2.4, U3.9 (SYS_RSTN)
ANT_RX: J3.5, U3.3 (RX)
ANT_SCL: J3.2, R4.2, U3.17 (SCL)
ANT_SDA: J3.3, R5.2, U3.16 (SDA)
ANT_TX: J3.4, U3.2 (TX)
ANT_VCC: C4.2, U1.5 (VCC), U3.14 (VCC_RF)
ANT_WK: J2.3, U3.5 (WAKE-UP)
GND: C1.2, C3.1, C4.1, C6.1, C7.2, D1.1 (A1), J1.2 (Ext), J2.1, J3.1, R3.2, U1.3 (GND), U1.7 (VSS), U3.1 (GND), U3.10 (GND_RF), U3.12 (GND_RF), U4.2 (GND), U4.4 (GND)
unnamed: C1.1, L1.2
unnamed: C2.1, D1.2 (A2), J1.1 (In), L1.1, R1.1
unnamed: R1.2, R2.2
unnamed: C2.2, L2.1, U1.1 (AI)
unnamed: U1.6 (AO), U4.1 (IN)
unnamed: C3.2, L2.2, U1.2 (BIAS)
unnamed: C5.2, R2.1, U3.11 (RF_IN)
unnamed: C5.1, U4.3 (OUT)

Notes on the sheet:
BGA725L6 stock (RF amplifier)
- BGA725L6 datasheet
BGA524N6 stock (RF amplifier)
TESEO-LIV3F project
B4327 stock (saw filter)
- B4327 datasheet
TESEO-LIV3F schematic



Board: 4 copper layers, 39.5 x 25.4 mm, 21 parts (4 on the bottom side), 19 nets.

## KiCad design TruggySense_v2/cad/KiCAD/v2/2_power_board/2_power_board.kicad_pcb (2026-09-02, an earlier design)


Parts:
C1: 1000µ; CP_Radial_D16.0mm_P7.50mm
C2: 1µ; C_0805_2012Metric_Pad1.18x1.45mm_HandSolder
C3: 100n; C_0805_2012Metric_Pad1.18x1.45mm_HandSolder
C4: 10µ; C_0805_2012Metric_Pad1.18x1.45mm_HandSolder
D1: VSSAF5M10HM3; DIOM5226X100N
J1: BAT; EC5_cable_pads
J2: ESC; EC5_cable_pads
J3: High_I_Sens; JST_XH_B3B-XH-A_1x03_P2.50mm_Vertical
J5: TMDC 20-2411; TerminalBlock_Phoenix_MKDS-1,5-2-5.08_1x02_P5.08mm_Horizont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
R1: 8k2; R_0805_2012Metric_Pad1.20x1.40mm_HandSolder
U1: ACS758xCB-200B-PFF; Allegro_CB_PFF

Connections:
+3.3V: C3.2, J3.2, U1.1 (VCC)
GND: C2.1, C3.1, J3.1, U1.2 (GND)
unnamed: J2.1 (V+), U1.5 (IP-)
unnamed: C2.2, J3.3, R1.2
unnamed: R1.1, U1.3 (VIOUT)
VBAT+: C1.1, D1.2 (A), J1.1 (V+), U1.4 (IP+)
VBAT-: C1.2, C4.2, J1.2 (V-), J2.2 (V-), J5.1
VTMDC: C4.1, D1.1 (K), J5.2

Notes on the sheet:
f_c = 1/ ( 2*pi*R*C ) <=> R = 1/ ( 2*pi*f_c*C ) R = 1/ ( 2*pi*20Hz*1µF ) = 7k9 -> 8k2 f_c = 19.4Hz


Board: 2 copper layers, 67.0 x 47.0 mm, 11 parts (0 on the bottom side), 8 nets.

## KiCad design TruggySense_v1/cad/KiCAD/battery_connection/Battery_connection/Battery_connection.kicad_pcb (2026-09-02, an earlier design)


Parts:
C1: 1µ; C_0805_2012Metric_Pad1.18x1.45mm_HandSolder
C2: 100n; C_0805_2012Metric_Pad1.18x1.45mm_HandSolder
C3: 1000µ; CP_Radial_D16.0mm_P7.50mm
C4, C5, C6, C7: 10µ; C_0805_2012Metric_Pad1.18x1.45mm_HandSolder
C8: 10µ; C_1206_3216Metric_Pad1.33x1.80mm_HandSolder
D1, D2, D3, D4: VSSAF5M10HM3; SODFL5226X100N
D5, D6, D7, D8: 1N4007; D_SMA_Handsoldering
J1: Supply_I_Sens; PinHeader_1x03_P2.54mm_Vertical
J2: ESC-; SolderWirePad_1x01_SMD_5x10mm
J3: ESC+; SolderWirePad_1x01_SMD_5x10mm
J4: BAT-; SolderWirePad_1x01_SMD_5x10mm
J5: BAT+; SolderWirePad_1x01_SMD_5x10mm
J6: JET_5V; TerminalBlock_Phoenix_MKDS-1,5-2-5.08_1x02_P5.08mm_Horizont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
J7: TEENSY_3V3; TerminalBlock_Phoenix_MKDS-1,5-2-5.08_1x02_P5.08mm_Horizont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
J8: PHERI_3V3; TerminalBlock_Phoenix_MKDS-1,5-2-5.08_1x02_P5.08mm_Horizont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
J9: PHERI_5V; TerminalBlock_Phoenix_MKDS-1,5-2-5.08_1x02_P5.08mm_Horizont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
R1: 8k2; R_0805_2012Metric_Pad1.20x1.40mm_HandSolder
U1: ACS758xCB-200B-PFF; Allegro_CB_PFF

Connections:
+3.3V: C2.2, J1.2, U1.1 (VCC)
GND: C3.2, C4.2, C5.2, C6.2, C7.2, C8.1, J2.1, J4.1, J6.1, J7.1, J8.1, J9.1
GND2: C1.1, C2.1, J1.3, U1.2 (GND)
unnamed: C7.1, D1.1 (K), D8.1 (K), J6.2
unnamed: C6.1, D2.1 (K), D7.1 (K), J9.2
unnamed: C5.1, D3.1 (K), D6.1 (K), J7.2
unnamed: C4.1, D4.1 (K), D5.1 (K), J8.2
unnamed: C1.2, J1.1, R1.2
unnamed: J3.1, U1.5 (IP-)
unnamed: R1.1, U1.3 (VIOUT)
VCC: C3.1, C8.2, D1.2 (A), D2.2 (A), D3.2 (A), D4.2 (A), D5.2 (A), D6.2 (A), D7.2 (A), D8.2 (A), J5.1, U1.4 (IP+)

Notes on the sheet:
f_c = 1/ ( 2*pi*R*C ) <=> R = 1/ ( 2*pi*f_c*C ) R = 1/ ( 2*pi*20Hz*1µF ) = 7k9 -> 8k2 f_c = 19.4Hz



Board: 2 copper layers, 66.0 x 46.0 mm, 27 parts (20 on the bottom side), 11 nets.

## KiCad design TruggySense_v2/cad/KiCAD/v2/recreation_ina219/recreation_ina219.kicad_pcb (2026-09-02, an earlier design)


Board: 2 copper layers, 25.4 x 22.4 mm, 11 parts (0 on the bottom side), 8 nets.

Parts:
C1: 100nF; C_0805_2012Metric_Pad1.18x1.45mm_HandSolder
J1: IN; TerminalBlock_Phoenix_PT-1,5-2-3.5-H_1x02_P3.50mm_Horizontal
J2: IO; PinHeader_1x06_P2.54mm_Vertical
JP1: A0; SolderJumper-2_P1.3mm_Open_TrianglePad1.0x1.5mm
JP2: A1; SolderJumper-2_P1.3mm_Open_TrianglePad1.0x1.5mm
R1, R2: 10k; R_0805_2012Metric_Pad1.20x1.40mm_HandSolder
R3, R4: 4k7; R_0805_2012Metric_Pad1.20x1.40mm_HandSolder
R5: 100m; R_2512_6332Metric_Pad1.40x3.35mm_HandSolder
U1: INA219AxDCN; SOT-23-8

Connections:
+3V3: C1.1, J2.1, JP1.2 (B), JP2.2 (B), R3.1, R4.1, U1.4 (VS)
GND: C1.2, J2.2, R1.2, R2.2, U1.3 (GND)
IN+: J1.1, J2.6, R5.1, U1.1 (IN+)
IN-: J1.2, J2.5, R5.2, U1.2 (IN-)
unnamed: JP1.1 (A), R1.1, U1.7 (A0)
unnamed: JP2.1 (A), R2.1, U1.8 (A1)
SCL: J2.3, R3.2, U1.5 (SCL)
SDA: J2.4, R4.2, U1.6 (SDA)

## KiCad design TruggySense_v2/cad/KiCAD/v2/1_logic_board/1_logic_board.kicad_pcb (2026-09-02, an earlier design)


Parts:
C1, C4, C6: 100nF; C_0805_2012Metric_Pad1.18x1.45mm_HandSolder
C2, C7: 10µF; C_0805_2012Metric_Pad1.18x1.45mm_HandSolder
C3: 1000µF; CP_Radial_D10.0mm_P5.00mm
C5: 47µF; CP_Radial_D8.0mm_P3.50mm
C8: 470µF; CP_Radial_D10.0mm_P5.00mm
D1: LED; LED_PLCC-2_3.4x3.0mm_AK
J1: TMDC_Input; TerminalBlock_Phoenix_MKDS-1,5-2-5.08_1x02_P5.08mm_Horizont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
J2: Jetson_Connector; TerminalBlock_Phoenix_MKDS-1,5-2-5.08_1x02_P5.08mm_Horizont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
JP1: 3V3_choice; SolderJumper-3_P2.0mm_Open_TrianglePad1.0x1.5mm_NumberLabels
Q1: 2N7002; SOT-23
R1, R2: 1k; R_0805_2012Metric_Pad1.20x1.40mm_HandSolder
R3: 10k; R_0805_2012Metric_Pad1.20x1.40mm_HandSolder
U1: Teensy4.1; Teensy41

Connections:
+3V3: C4.1, C5.1, JP1.2 (C), R1.2; also elsewhere on the board
+3V3_CONV: JP1.3 (B); also elsewhere on the board
+3V3_LLC: JP1.1 (A), U1.15 (3V3), U1.46 (3V3), U1.51 (3V3)
+5V: C1.1, C2.1, C3.1, J1.2; also elsewhere on the board
+5V_HLC: C6.1, C7.1, C8.1, J2.2, U1.55 (5V); also elsewhere on the board
+5V_LLC: U1.48 (VIN), U1.49 (VUSB); also elsewhere on the board
ADC_38: U1.30 (38_CS1_IN1); also elsewhere on the board
ADC_39: U1.31 (39_MISO1_OUT1A); also elsewhere on the board
ADC_I_M_FL: U1.21 (29_TX7); also elsewhere on the board
ADC_I_M_FR: U1.20 (28_RX7); also elsewhere on the board
ADC_I_M_RL: U1.23 (31_CTX3); also elsewhere on the board
ADC_I_M_RR: U1.22 (30_CRX3); also elsewhere on the board
ADC_PWM_22: U1.44 (22_A8_CTX1); also elsewhere on the board
ADC_PWM_23: U1.45 (23_A9_CRX1_MCLK1); also elsewhere on the board
ADC_V_3.3: U1.32 (40_A16); also elsewhere on the board
ADC_V_5.0: U1.33 (41_A17); also elsewhere on the board
ADC_V_B_C1: U1.36 (14_A0_TX3_SPDIF_OUT); also elsewhere on the board
ADC_V_B_C2: U1.37 (15_A1_RX3_SPDIF_IN); also elsewhere on the board
ADC_V_B_C3: U1.38 (16_A2_RX4_SCL1); also elsewhere on the board
ADC_V_B_C4: U1.39 (17_A3_TX4_SDA1); also elsewhere on the board
ETH_LED: U1.61 (LED); also elsewhere on the board
ETH_R+: U1.60 (R+); also elsewhere on the board
ETH_R-: U1.65 (R-); also elsewhere on the board
ETH_T+: U1.63 (T+); also elsewhere on the board
ETH_T-: U1.62 (T-); also elsewhere on the board
GND: C1.2, C2.2, C3.2, C4.2, C5.2, C6.2, C7.2, C8.2, J1.1, J2.1, Q1.2 (S), R3.2, U1.1 (GND), U1.34 (GND), U1.47 (GND), U1.52 (GND), U1.58 (GND), U1.59 (GND), U1.64 (GND); also elsewhere on the board
HALL_W_FL: U1.17 (25_A11_RX6_SDA2); also elsewhere on the board
HALL_W_FR: U1.16 (24_A10_TX6_SCL2); also elsewhere on the board
HALL_W_RL: U1.19 (27_A13_SCK1); also elsewhere on the board
HALL_W_RR: U1.18 (26_A12_MOSI1); also elsewhere on the board
I2C_SCL: U1.41 (19_A5_SCL); also elsewhere on the board
I2C_SDA: U1.40 (18_A4_SDA); also elsewhere on the board
LED_1: R2.1, U1.24 (32_OUT1B); also elsewhere on the board
unnamed: D1.2 (A), R1.1
unnamed: D1.1 (K), Q1.3 (D)
unnamed: Q1.1 (G), R2.2, R3.1
PWM_33: U1.25 (33_MCLK2); also elsewhere on the board
PWM_36: U1.28 (36_CS); also elsewhere on the board
PWM_37: U1.29 (37_CS); also elsewhere on the board
PWM_M_FL: U1.6 (4_BCLK2); also elsewhere on the board
PWM_M_FR: U1.5 (3_LRCLK2); also elsewhere on the board
PWM_M_RL: U1.8 (6_OUT1D); also elsewhere on the board
PWM_M_RR: U1.7 (5_IN2); also elsewhere on the board
PWM_SERVO: U1.4 (2_OUT2); also elsewhere on the board
SPI_CE: U1.11 (9_OUT1C); also elsewhere on the board
SPI_CS: U1.12 (10_CS_MQSR); also elsewhere on the board
SPI_MISO: U1.14 (12_MISO_MQSL); also elsewhere on the board
SPI_MOSI: U1.13 (11_MOSI_CTX1); also elsewhere on the board
SPI_SCK: U1.35 (13_SCK_LED); also elsewhere on the board
UART_GPS_RX: U1.42 (20_A6_TX5_LRCLK1); also elsewhere on the board
UART_GPS_TX: U1.43 (21_A7_RX5_BCLK1); also elsewhere on the board
UART_IBUS_RX: U1.27 (35_TX8); also elsewhere on the board
UART_IBUS_TX: U1.26 (34_RX8); also elsewhere on the board
UART_USB_RX: U1.10 (8_TX2_IN1); also elsewhere on the board
UART_USB_TX: U1.9 (7_RX2_OUT1A); also elsewhere on the board
USB_HOST_D+: U1.57 (D+); also elsewhere on the board
USB_HOST_D-: U1.56 (D-); also elsewhere on the board

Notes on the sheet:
https://www.pjrc.com/teensy/card11b_rev4_web.pdf
https://www.pjrc.com/teensy/card11a_rev4_web.pdf

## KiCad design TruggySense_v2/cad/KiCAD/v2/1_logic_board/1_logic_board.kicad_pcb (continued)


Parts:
J12: PWM_SERVO; JST_XH_B3B-XH-A_1x03_P2.50mm_Vertical
J13: ESC_MOTOR_FR; JST_XH_B3B-XH-A_1x03_P2.50mm_Vertical
J14: ESC_MOTOR_FL; JST_XH_B3B-XH-A_1x03_P2.50mm_Vertical
J15: ESC_MOTOR_RR; JST_XH_B3B-XH-A_1x03_P2.50mm_Vertical
J16: ESC_MOTOR_RL; JST_XH_B3B-XH-A_1x03_P2.50mm_Vertical

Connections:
/PWM/IO_Protection/GND_OUT_1: J12.1; also elsewhere on the board
/PWM/IO_Protection/GND_OUT_2: J13.1; also elsewhere on the board
/PWM/IO_Protection/GND_OUT_3: J14.1; also elsewhere on the board
/PWM/IO_Protection/GND_OUT_4: J15.1; also elsewhere on the board
/PWM/IO_Protection/GND_OUT_5: J16.1; also elsewhere on the board
/PWM/IO_Protection/OUT_1: J12.3; also elsewhere on the board
/PWM/IO_Protection/OUT_2: J13.3; also elsewhere on the board
/PWM/IO_Protection/OUT_3: J14.3; also elsewhere on the board
/PWM/IO_Protection/OUT_4: J15.3; also elsewhere on the board
/PWM/IO_Protection/OUT_5: J16.3; also elsewhere on the board
/PWM/IO_Protection/VCC_OUT_1: J12.2; also elsewhere on the board
/PWM/IO_Protection/VCC_OUT_2: J13.2; also elsewhere on the board
/PWM/IO_Protection/VCC_OUT_3: J14.2; also elsewhere on the board
/PWM/IO_Protection/VCC_OUT_4: J15.2; also elsewhere on the board
/PWM/IO_Protection/VCC_OUT_5: J16.2; also elsewhere on the board

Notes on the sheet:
https://myosuploads3.banggood.com/products/20220907/20220907032153DS3225datasheet.pdf
https://www.scribd.com/document/740954956/DS3225-datasheet


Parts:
C13, C21, C23, C27, C31, C35, C39: 1µF; C_0805_2012Metric_Pad1.18x1.45mm_HandSolder
C14, C22, C28, C32, C36, C40: 100nF; C_0805_2012Metric_Pad1.18x1.45mm_HandSolder
C15: 2.2µF; C_0805_2012Metric_Pad1.18x1.45mm_HandSolder
C16: 470nF; C_0805_2012Metric_Pad1.18x1.45mm_HandSolder
C17: 3.3µF; C_0805_2012Metric_Pad1.18x1.45mm_HandSolder
C18: 820nF; C_0805_2012Metric_Pad1.18x1.45mm_HandSolder
C19: 4.7µF; C_0805_2012Metric_Pad1.18x1.45mm_HandSolder
C20, C24: 680nF; C_0805_2012Metric_Pad1.18x1.45mm_HandSolder
C25, C29, C33, C37: 10nF; C_0805_2012Metric_Pad1.18x1.45mm_HandSolder
C26, C30, C34, C38: 10µF; C_0805_2012Metric_Pad1.18x1.45mm_HandSolder
J7: V_BMS; JST_XH_B5B-XH-A_1x05_P2.50mm_Vertical
J8: I_M_FR; JST_XH_B3B-XH-A_1x03_P2.50mm_Vertical
J9: I_M_FL; JST_XH_B3B-XH-A_1x03_P2.50mm_Vertical
J10: I_M_RR; JST_XH_B3B-XH-A_1x03_P2.50mm_Vertical
J11: I_M_RL; JST_XH_B3B-XH-A_1x03_P2.50mm_Vertical
JP2: V_MCU; SolderJumper-2_P1.3mm_Open_RoundedPad1.0x1.5mm
JP3: V_JET; SolderJumper-2_P1.3mm_Open_RoundedPad1.0x1.5mm
R7, R10, R13, R16, R19, R22, R25, R28, R31, R34: 10k; R_0805_2012Metric_Pad1.20x1.40mm_HandSolder
R8: 33k; R_0805_2012Metric_Pad1.20x1.40mm_HandSolder
R9: 3k9; R_0805_2012Metric_Pad1.20x1.40mm_HandSolder
R11, R24: 5k6; R_0805_2012Metric_Pad1.20x1.40mm_HandSolder
R12: 820; R_0805_2012Metric_Pad1.20x1.40mm_HandSolder
R14: 3k3; R_0805_2012Metric_Pad1.20x1.40mm_HandSolder
R15, R18: 220; R_0805_2012Metric_Pad1.20x1.40mm_HandSolder
R17: 2k2; R_0805_2012Metric_Pad1.20x1.40mm_HandSolder
R20, R26, R29, R32, R35: 150k; R_0805_2012Metric_Pad1.20x1.40mm_HandSolder
R21, R27, R30, R33, R36: 15k; R_0805_2012Metric_Pad1.20x1.40mm_HandSolder
R23: 12k; R_0805_2012Metric_Pad1.20x1.40mm_HandSolder

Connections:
+3V3: C25.1, C26.1, C29.1, C30.1, C33.1, C34.1, C37.1, C38.1, J8.2, J9.2, J10.2, J11.2, JP2.2 (B); also elsewhere on the board
+5V: JP3.2 (B); also elsewhere on the board
/ADC/IO_Protection/IN_1: C13.1, C14.1, R7.2, R8.1; also elsewhere on the board
/ADC/IO_Protection/IN_2: C15.1, C16.1, R10.2, R11.1; also elsewhere on the board
/ADC/IO_Protection/IN_3: C17.1, C18.1, R13.2, R14.1; also elsewhere on the board
/ADC/IO_Protection/IN_4: C19.1, C20.1, R16.2, R17.1; also elsewhere on the board
/ADC/IO_Protection/IN_5: C21.2, C22.1, R19.2, R20.1; also elsewhere on the board
/ADC/IO_Protection/IN_6: C23.2, C24.1, R22.2, R23.1; also elsewhere on the board
/ADC/IO_Protection/IN_7: C27.1, C28.1, R25.2, R26.1; also elsewhere on the board
/ADC/IO_Protection/IN_8: C31.1, C32.1, R28.2, R29.1; also elsewhere on the board
/ADC/IO_Protection/IN_9: C35.1, C36.1, R31.2, R32.1; also elsewhere on the board
/ADC/IO_Protection/IN_10: C39.1, C40.1, R34.2, R35.1; also elsewhere on the board
GND: C13.2, C14.2, C15.2, C16.2, C17.2, C18.2, C19.2, C20.2, C21.1, C22.2, C23.1, C24.2, C25.2, C26.2, C27.2, C28.2, C29.2, C30.2, C31.2, C32.2, C33.2, C34.2, C35.2, C36.2, C37.2, C38.2, C39.2, C40.2, J7.1, J8.3, J9.3, J10.3, J11.3, R9.2, R12.2, R15.2, R18.2, R21.2, R24.2, R27.2, R30.2, R33.2, R36.2; also elsewhere on the board
unnamed: J7.2, R7.1
unnamed: J7.3, R10.1
unnamed: J7.4, R13.1
unnamed: J7.5, R16.1
unnamed: J8.1, R25.1
unnamed: J9.1, R28.1
unnamed: J10.1, R31.1
unnamed: J11.1, R34.1
unnamed: JP2.1 (A), R19.1
unnamed: JP3.1 (A), R22.1
unnamed: R8.2, R9.1
unnamed: R11.2, R12.1
unnamed: R14.2, R15.1
unnamed: R17.2, R18.1
unnamed: R20.2, R21.1
unnamed: R23.2, R24.1
unnamed: R26.2, R27.1
unnamed: R29.2, R30.1
unnamed: R32.2, R33.1
unnamed: R35.2, R36.1

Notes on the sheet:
8.4
LPF: 15Hz
3.3
16.8
±0.62
12.6
4.2


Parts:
J39, J40: Conn_02x29_Odd_Even; PinHeader_2x29_P2.54mm_Vertical
TP1: USB_D-; Pin_D1.3mm_L11.0mm
TP2: ETH_R-; Pin_D1.3mm_L11.0mm
TP3: USB_D+; Pin_D1.3mm_L11.0mm
TP4: ETH_R+; Pin_D1.3mm_L11.0mm
TP5: ETH_T-; Pin_D1.3mm_L11.0mm
TP6: ETH_T+; Pin_D1.3mm_L11.0mm
TP7: PIN_02; Pin_D1.3mm_L11.0mm
TP8: PIN_03; Pin_D1.3mm_L11.0mm
TP9: PIN_04; Pin_D1.3mm_L11.0mm
TP10: PIN_23; Pin_D1.3mm_L11.0mm
TP11: PIN_05; Pin_D1.3mm_L11.0mm
TP12: PIN_22; Pin_D1.3mm_L11.0mm
TP13: PIN_06; Pin_D1.3mm_L11.0mm
TP14: PIN_21; Pin_D1.3mm_L11.0mm
TP15: PIN_07; Pin_D1.3mm_L11.0mm
TP16: PIN_19; Pin_D1.3mm_L11.0mm
TP17: PIN_08; Pin_D1.3mm_L11.0mm
TP18: PIN_18; Pin_D1.3mm_L11.0mm
TP19: PIN_09; Pin_D1.3mm_L11.0mm
TP20: PIN_17; Pin_D1.3mm_L11.0mm
TP21: PIN_10; Pin_D1.3mm_L11.0mm
TP22: PIN_16; Pin_D1.3mm_L11.0mm
TP23: PIN_11; Pin_D1.3mm_L11.0mm
TP24: PIN_15; Pin_D1.3mm_L11.0mm
TP25: PIN_12; Pin_D1.3mm_L11.0mm
TP26: PIN_14; Pin_D1.3mm_L11.0mm
TP27, TP28: PIN_13; Pin_D1.3mm_L11.0mm
TP29: PIN_24; Pin_D1.3mm_L11.0mm
TP30: PIN_41; Pin_D1.3mm_L11.0mm
TP31: PIN_25; Pin_D1.3mm_L11.0mm
TP32: PIN_40; Pin_D1.3mm_L11.0mm
TP33: PIN_26; Pin_D1.3mm_L11.0mm
TP34: PIN_39; Pin_D1.3mm_L11.0mm
TP35: PIN_27; Pin_D1.3mm_L11.0mm
TP36: PIN_38; Pin_D1.3mm_L11.0mm
TP37: PIN_28; Pin_D1.3mm_L11.0mm
TP38: PIN_37; Pin_D1.3mm_L11.0mm
TP39: PIN_29; Pin_D1.3mm_L11.0mm
TP40: PIN_36; Pin_D1.3mm_L11.0mm
TP41: PIN_30; Pin_D1.3mm_L11.0mm
TP42: PIN_35; Pin_D1.3mm_L11.0mm
TP43: PIN_31; Pin_D1.3mm_L11.0mm
TP44: PIN_34; Pin_D1.3mm_L11.0mm
TP45: PIN_32; Pin_D1.3mm_L11.0mm
TP46: PIN_33; Pin_D1.3mm_L11.0mm

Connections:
+3V3: J39.6, J39.34, J39.56, J40.9, J40.33, J40.55; also elsewhere on the board
+5V: J39.5, J39.33, J39.55, J40.10, J40.34, J40.56; also elsewhere on the board
ADC_38: J40.43, J40.44, TP36.1; also elsewhere on the board
ADC_39: J40.41, J40.42, TP34.1; also elsewhere on the board
ADC_I_M_FL: J39.47, J39.48, TP39.1; also elsewhere on the board
ADC_I_M_FR: J39.45, J39.46, TP37.1; also elsewhere on the board
ADC_I_M_RL: J39.51, J39.52, TP43.1; also elsewhere on the board
ADC_I_M_RR: J39.49, J39.50, TP41.1; also elsewhere on the board
ADC_PWM_22: J40.15, J40.16, TP12.1; also elsewhere on the board
ADC_PWM_23: J40.13, J40.14, TP10.1; also elsewhere on the board
ADC_V_3.3: J40.39, J40.40, TP32.1; also elsewhere on the board
ADC_V_5.0: J40.37, J40.38, TP30.1; also elsewhere on the board
ADC_V_B_C1: J40.31, J40.32, TP28.1; also elsewhere on the board
ADC_V_B_C2: J40.29, J40.30, TP26.1; also elsewhere on the board
ADC_V_B_C3: J40.27, J40.28, TP24.1; also elsewhere on the board
ADC_V_B_C4: J40.25, J40.26, TP22.1; also elsewhere on the board
ETH_R+: J40.3, J40.4, TP4.1; also elsewhere on the board
ETH_R-: J40.1, J40.2, TP2.1; also elsewhere on the board
ETH_T+: J40.7, J40.8, TP6.1; also elsewhere on the board
ETH_T-: J40.5, J40.6, TP5.1; also elsewhere on the board
GND: J39.7, J39.8, J39.35, J39.36, J39.57, J39.58, J40.11, J40.12, J40.35, J40.36, J40.57, J40.58; also elsewhere on the board
HALL_W_FL: J39.39, J39.40, TP31.1; also elsewhere on the board
HALL_W_FR: J39.37, J39.38, TP29.1; also elsewhere on the board
HALL_W_RL: J39.43, J39.44, TP35.1; also elsewhere on the board
HALL_W_RR: J39.41, J39.42, TP33.1; also elsewhere on the board
I2C_SCL: J40.21, J40.22, TP18.1; also elsewhere on the board
I2C_SDA: J40.23, J40.24, TP20.1; also elsewhere on the board
LED_1: J39.53, J39.54, TP45.1; also elsewhere on the board
PWM_33: J40.53, J40.54, TP46.1; also elsewhere on the board
PWM_36: J40.47, J40.48, TP40.1; also elsewhere on the board
PWM_37: J40.45, J40.46, TP38.1; also elsewhere on the board
PWM_M_FL: J39.13, J39.14, TP9.1; also elsewhere on the board
PWM_M_FR: J39.11, J39.12, TP8.1; also elsewhere on the board
PWM_M_RL: J39.17, J39.18, TP13.1; also elsewhere on the board
PWM_M_RR: J39.15, J39.16, TP11.1; also elsewhere on the board
PWM_SERVO: J39.9, J39.10, TP7.1; also elsewhere on the board
SPI_CE: J39.23, J39.24, TP19.1; also elsewhere on the board
SPI_CS: J39.25, J39.26, TP21.1; also elsewhere on the board
SPI_MISO: J39.29, J39.30, TP25.1; also elsewhere on the board
SPI_MOSI: J39.27, J39.28, TP23.1; also elsewhere on the board
SPI_SCK: J39.31, J39.32, TP27.1; also elsewhere on the board
UART_GPS_RX: J40.19, J40.20, TP16.1; also elsewhere on the board
UART_GPS_TX: J40.17, J40.18, TP14.1; also elsewhere on the board
UART_IBUS_RX: J40.49, J40.50, TP42.1; also elsewhere on the board
UART_IBUS_TX: J40.51, J40.52, TP44.1; also elsewhere on the board
UART_USB_RX: J39.21, J39.22, TP17.1; also elsewhere on the board
UART_USB_TX: J39.19, J39.20, TP15.1; also elsewhere on the board
USB_HOST_D+: J39.3, J39.4, TP3.1; also elsewhere on the board
USB_HOST_D-: J39.1, J39.2, TP1.1; also elsewhere on the board


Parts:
C41, C43: 100nF; C_0805_2012Metric_Pad1.18x1.45mm_HandSolder
C42, C44: 10µF; C_0805_2012Metric_Pad1.18x1.45mm_HandSolder
J17: I2C Connector; JST_XH_B4B-XH-A_1x04_P2.50mm_Vertical
J18: I2C_Temperature_Connector; JST_XH_B5B-XH-A_1x05_P2.50mm_Vertical
R37, R38: 4k7; R_0805_2012Metric_Pad1.20x1.40mm_HandSolder

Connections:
+3V3: C41.1, C42.1, C43.1, C44.1, J17.4, J18.5, R37.2, R38.1; also elsewhere on the board
GND: C41.2, C42.2, C43.2, C44.2, J17.1, J18.1; also elsewhere on the board
GPS_SCL: J17.2, J18.3; also elsewhere on the board
GPS_SDA: J17.3, J18.4; also elsewhere on the board
I2C_SCL: R38.2; also elsewhere on the board
I2C_SDA: R37.1; also elsewhere on the board

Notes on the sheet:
PIM448 (ICM-20948)
LM75


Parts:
C50, C52, C54, C56, C60, C61, C62: 100nF; C_0805_2012Metric_Pad1.18x1.45mm_HandSolder
C51, C53, C55, C57: 10µF; C_0805_2012Metric_Pad1.18x1.45mm_HandSolder
C58: 4.7µF; C_0805_2012Metric_Pad1.18x1.45mm_HandSolder
C59: 10nF; C_0805_2012Metric_Pad1.18x1.45mm_HandSolder
J23: Encoder_Motor_FR; JST_XH_B3B-XH-A_1x03_P2.50mm_Vertical
J24: Encoder_Motor_FL; JST_XH_B3B-XH-A_1x03_P2.50mm_Vertical
J25: Encoder_Motor_RR; JST_XH_B3B-XH-A_1x03_P2.50mm_Vertical
J26: Encoder_Motor_RL; JST_XH_B3B-XH-A_1x03_P2.50mm_Vertical
J27: Micro_USB; PinHeader_1x05_P2.54mm_Vertical
J28: ARJM11B1-009-AB-EW2; CONN12_ARJM11B1-009-AB-EW2_ABR
JP5: USB_D-_choice; SolderJumper-3_P2.0mm_Open_TrianglePad1.0x1.5mm_NumberLabels
JP6: USB_D+_choice; SolderJumper-3_P2.0mm_Open_TrianglePad1.0x1.5mm_NumberLabels
R48, R49, R50, R51: 10k; R_0805_2012Metric_Pad1.20x1.40mm_HandSolder
R52: 220; R_0805_2012Metric_Pad1.20x1.40mm_HandSolder
U3: FT232RL; SSOP-28_5.3x10.2mm_P0.65mm

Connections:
+3V3: C50.1, C51.1, C52.1, C53.1, C54.1, C55.1, C56.1, C57.1, J23.3, J24.3, J25.3, J26.3, R48.2, R49.2, R50.2, R51.2; also elsewhere on the board
+5V_HLC: C58.1, C59.1, C60.1, J27.1, U3.4 (VCCIO), U3.20 (VCC); also elsewhere on the board
/Various Inputs/IO_Protection/IN_1: J23.1, R48.1; also elsewhere on the board
/Various Inputs/IO_Protection/IN_2: J24.1, R49.1; also elsewhere on the board
/Various Inputs/IO_Protection/IN_3: J25.1, R50.1; also elsewhere on the board
/Various Inputs/IO_Protection/IN_4: J26.1, R51.1; also elsewhere on the board
ETH_LED: J28.9; also elsewhere on the board
ETH_R+: J28.3 (RD+); also elsewhere on the board
ETH_R-: J28.6 (RD-); also elsewhere on the board
ETH_T+: J28.1 (TD+); also elsewhere on the board
ETH_T-: J28.2 (TD-); also elsewhere on the board
GND: C50.2, C51.2, C52.2, C53.2, C54.2, C55.2, C56.2, C57.2, C58.2, C59.2, C60.2, C61.2, C62.2, J23.2, J24.2, J25.2, J26.2, J27.4, J27.5, J28.8, J28.SH, R52.1, U3.7 (GND), U3.18 (GND), U3.21 (GND), U3.25 (AGND), U3.26 (TEST); also elsewhere on the board
unnamed: J27.2, JP5.2 (C)
unnamed: J27.3, JP6.2 (C)
unnamed: J28.10, R52.2
unnamed: C62.1, J28.4 (TCT), J28.5 (RCT)
unnamed: JP5.1 (A), U3.16 (USBD-)
unnamed: JP6.1 (A), U3.15 (USBD+)
unnamed: C61.1, U3.17 (3V3OUT)
USB_CHIP_RX: U3.5 (RXD); also elsewhere on the board
USB_CHIP_TX: U3.1 (TXD); also elsewhere on the board
USB_HOST_D+: JP6.3 (B); also elsewhere on the board
USB_HOST_D-: JP5.3 (B); also elsewhere on the board

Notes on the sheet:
https://www.pjrc.com/store/ethernet_kit.html
Ethernet
USB
Rotary Encoder


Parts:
C3.1: 33nF; C_0805_2012Metric_Pad1.18x1.45mm_HandSolder
C3.2: 47nF; C_0805_2012Metric_Pad1.18x1.45mm_HandSolder
C11: 100µF; CP_Radial_D5.0mm_P2.00mm
C12: 220µF; CP_Radial_D6.3mm_P2.50mm
D2: SK34; D_SMA_Handsoldering
J3: VIN+; PinHeader_1x01_P2.54mm_Vertical
J4: VOUT+; PinHeader_1x01_P2.54mm_Vertical
J5: VIN-; PinHeader_1x01_P2.54mm_Vertical
J6: VOUT-; PinHeader_1x01_P2.54mm_Vertical
L1: 15µH; 29153C
R2.1: 680; R_0805_2012Metric_Pad1.20x1.40mm_HandSolder
R2.2, R6: 1k; R_0805_2012Metric_Pad1.20x1.40mm_HandSolder
U2: LM2596S-ADJ; TO-263-5_TabPin3

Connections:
+3V3_CONV: C3.2.2, C12.1, J4.1, L1.2, R2.2.1; also elsewhere on the board
+5V_LLC: C11.1, J3.1, U2.1 (VIN); also elsewhere on the board
GND: C11.2, C12.2, D2.2 (A), J5.1, J6.1, R6.1, U2.3 (GND), U2.5 (~ON/OFF); also elsewhere on the board
unnamed: C3.1.2, C3.2.1
unnamed: D2.1 (K), L1.1, U2.2 (OUT)
unnamed: R2.1.1, R2.2.2
unnamed: C3.1.1, R2.1.2, R6.2, U2.4 (FB)

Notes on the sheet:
V_{SAT} = 1.16V V_{D} = V_{F} = 0.525V E*T = (V_{IN} - V_{OUT} - V_{SAT})[(V_{OUT} + V_{D})/(V_{IN} - V_{SAT} + V_{D)}](1/150kHz) = (5V - 3.3V - 1.16V)[(3.3V + 0.525V)/(5V - 1.16V + 0.525V)](1/150kHz) = 0.54V * [3.825V/4.365V] * 6.667µs = 3.15 V*µs Then get L1 out of figure9-8 (link attached) L1 = 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
V_{REF} = 1.23V V_{OUT} = V_{REF} * (1 + R2/R1) R2 = R1 * (V_{OUT}/V_{REF} - 1) = 1kΩ * (3.3V/1.23V - 1) = 1.68kΩ R2.1 = 1kΩ R2.2 = 0.68kΩ
https://htckorea.co.kr/image/DK/LM2596_Module_R1.0.pdf
C_{FF} = C3 = 1/(31 * 10^{3} * R2) = 1/(31 * 10^{3} * 1.68kΩ) = 19.2nF C3.1 = 33nF C3.2 = 47nF C3 = 1/[(1/C3.1)+(1/C3.2)] = 1/[(1/33nF)+(1/47nF)] = 19.388nF


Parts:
C45, C47: 100nF; C_0805_2012Metric_Pad1.18x1.45mm_HandSolder
C46, C48: 10µF; C_0805_2012Metric_Pad1.18x1.45mm_HandSolder
C49: 47µF; CP_Radial_D8.0mm_P3.50mm
D3: M1; D_SMA_Handsoldering
J19: IBUS; JST_XH_B3B-XH-A_1x03_P2.50mm_Vertical
J20, J21: GPS_IO; PinHeader_1x05_P2.54mm_Vertical
J22: UART_USB; PinHeader_1x03_P2.54mm_Vertical
JP4: IBUS; SolderJumper-2_P1.3mm_Open_RoundedPad1.0x1.5mm
Q2: 2N7002; SOT-23
Q3, Q4, Q5: BCW71; SOT-23
R39, R40, R41: 10k; R_0805_2012Metric_Pad1.20x1.40mm_HandSolder
R42, R43, R44, R45, R46: 1k; R_0805_2012Metric_Pad1.20x1.40mm_HandSolder
R47: 1k8; R_0805_2012Metric_Pad1.20x1.40mm_HandSolder

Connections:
+3V3: C47.1, C48.1, C49.1, J20.5, Q2.1 (G), R41.2; also elsewhere on the board
+5V_HLC: R42.1, R43.1; also elsewhere on the board
+5V_RCC: C45.1, C46.1, J19.2, R40.2; also elsewhere on the board
/UART/IO_Protection/IN_1: D3.1 (K), R39.2; also elsewhere on the board
/UART/IO_Protection/IN_2: JP4.1 (A), Q3.3 (C); also elsewhere on the board
/UART/IO_Protection/IN_3: J21.5; also elsewhere on the board
/UART/IO_Protection/IN_4: J21.4; also elsewhere on the board
/UART/IO_Protection/IN_5: R45.2; also elsewhere on the board
/UART/IO_Protection/IN_6: R46.1, R47.2; also elsewhere on the board
GND: C45.2, C46.2, C47.2, C48.2, C49.2, J19.3, J20.1, J21.1, J22.1, Q4.2 (E), Q5.2 (E), R47.1; also elsewhere on the board
GPS_PPS: J20.2
GPS_RST: J20.4
GPS_SCL: J21.2; also elsewhere on the board
GPS_SDA: J21.3; also elsewhere on the board
GPS_WK: J20.3
unnamed: D3.2 (A), JP4.2 (B), Q2.2 (S), Q3.2 (E), R41.1
unnamed: J19.1, Q2.3 (D), R40.1
unnamed: Q3.1 (B), R39.1
unnamed: Q4.1 (B), R44.1
unnamed: Q5.1 (B), R45.1
unnamed: Q5.3 (C), R43.2, R44.2
USB_CHIP_RX: J22.2, Q4.3 (C), R42.2; also elsewhere on the board
USB_CHIP_TX: J22.3, R46.2; also elsewhere on the board

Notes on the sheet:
GND
SCL
PPS
https://electronics.stackexchange.com/a/186182
RST
3V3
SDA
GPS
USB
FlySky

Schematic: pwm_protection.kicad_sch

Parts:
C76, C78, C80, C82, C84: 100nF; C_0805_2012Metric_Pad1.18x1.45mm_HandSolder
C77, C79, C81, C83, C85: 470µF; CP_Radial_D10.0mm_P5.00mm
JP15, JP17, JP19, JP21, JP23: PWM_VCC; SolderJumper-2_P1.3mm_Open_RoundedPad1.0x1.5mm
JP16, JP18, JP20, JP22, JP24: PWM_GND; SolderJumper-2_P1.3mm_Open_RoundedPad1.0x1.5mm

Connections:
+5V_RCC: JP15.1 (A), JP17.1 (A), JP19.1 (A), JP21.1 (A), JP23.1 (A); also elsewhere on the board
/PWM/IO_Protection/GND_OUT_1: C76.2, C77.2, JP16.1 (A); also elsewhere on the board
/PWM/IO_Protection/GND_OUT_2: C78.2, C79.2, JP18.1 (A); also elsewhere on the board
/PWM/IO_Protection/GND_OUT_3: C80.2, C81.2, JP20.1 (A); also elsewhere on the board
/PWM/IO_Protection/GND_OUT_4: C82.2, C83.2, JP22.1 (A); also elsewhere on the board
/PWM/IO_Protection/GND_OUT_5: C84.2, C85.2, JP24.1 (A); also elsewhere on the board
/PWM/IO_Protection/VCC_OUT_1: C76.1, C77.1, JP15.2 (B); also elsewhere on the board
/PWM/IO_Protection/VCC_OUT_2: C78.1, C79.1, JP17.2 (B); also elsewhere on the board
/PWM/IO_Protection/VCC_OUT_3: C80.1, C81.1, JP19.2 (B); also elsewhere on the board
/PWM/IO_Protection/VCC_OUT_4: C82.1, C83.1, JP21.2 (B); also elsewhere on the board
/PWM/IO_Protection/VCC_OUT_5: C84.1, C85.1, JP23.2 (B); also elsewhere on the board
GND: JP16.2 (B), JP18.2 (B), JP20.2 (B), JP22.2 (B), JP24.2 (B); also elsewhere on the board

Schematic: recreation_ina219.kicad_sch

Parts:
C65: 100nF; C_0805_2012Metric_Pad1.18x1.45mm_HandSolder
C66: 4.7µF; C_0805_2012Metric_Pad1.18x1.45mm_HandSolder
J30: IN; TerminalBlock_Phoenix_PT-1,5-2-3.5-H_1x02_P3.50mm_Horizontal
J31: INA_IO; PinHeader_1x06_P2.54mm_Vertical
JP7: A1; SolderJumper-2_P1.3mm_Open_RoundedPad1.0x1.5mm
JP8: A0; SolderJumper-2_P1.3mm_Open_RoundedPad1.0x1.5mm
R53, R54, R56, R57: 10k; R_0805_2012Metric_Pad1.20x1.40mm_HandSolder
R55: 100m; R_2512_6332Metric_Pad1.40x3.35mm_HandSolder
U4: INA219AxDCN; SOT-23-8

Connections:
+3V3: C65.1, C66.1, J31.1, JP7.2 (B), JP8.2 (B), R53.1, R54.1, U4.4 (VS); also elsewhere on the board
/I2C/Low_Current_TMDC/IN+: J30.1, J31.6, R55.1, U4.1 (IN+)
/I2C/Low_Current_TMDC/IN-: J30.2, J31.5, R55.2, U4.2 (IN-)
GND: C65.2, C66.2, J31.2, R56.2, R57.2, U4.3 (GND); also elsewhere on the board
GPS_SCL: J31.3, R54.2, U4.5 (SCL); also elsewhere on the board
GPS_SDA: J31.4, R53.2, U4.6 (SDA); also elsewhere on the board
unnamed: JP7.1 (A), R56.1, U4.8 (A1)
unnamed: JP8.1 (A), R57.1, U4.7 (A0)

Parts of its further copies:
C67, C69, C71: 100nF; C_0805_2012Metric_Pad1.18x1.45mm_HandSolder
C68, C70, C72: 4.7µF; C_0805_2012Metric_Pad1.18x1.45mm_HandSolder
J32, J34, J36: IN; TerminalBlock_Phoenix_PT-1,5-2-3.5-H_1x02_P3.50mm_Horizontal
J33, J35, J37: INA_IO; PinHeader_1x06_P2.54mm_Vertical
JP9, JP11, JP13: A1; SolderJumper-2_P1.3mm_Open_RoundedPad1.0x1.5mm
JP10, JP12, JP14: A0; SolderJumper-2_P1.3mm_Open_RoundedPad1.0x1.5mm
R58, R59, R61, R62, R63, R64, R66, R67, R68, R69, R71, R72: 10k; R_0805_2012Metric_Pad1.20x1.40mm_HandSolder
R60, R65, R70: 100m; R_2512_6332Metric_Pad1.40x3.35mm_HandSolder
U5, U6, U7: INA219AxDCN; SOT-23-8

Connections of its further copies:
+3V3: C67.1, C68.1, C69.1, C70.1, C71.1, C72.1, J33.1, J35.1, J37.1, JP9.2 (B), JP10.2 (B), JP11.2 (B), JP12.2 (B), JP13.2 (B), JP14.2 (B), R58.1, R59.1, R63.1, R64.1, R68.1, R69.1, U5.4 (VS), U6.4 (VS), U7.4 (VS); also elsewhere on the board
+5V: J32.1, J33.6, J34.1, J35.6, J36.1, J37.6, R60.1, R65.1, R70.1, U5.1 (IN+), U6.1 (IN+), U7.1 (IN+); also elsewhere on the board
+5V_HLC: J32.2, J33.5, R60.2, U5.2 (IN-); also elsewhere on the board
+5V_LLC: J36.2, J37.5, R70.2, U7.2 (IN-); also elsewhere on the board
+5V_RCC: J34.2, J35.5, R65.2, U6.2 (IN-); also elsewhere on the board
GND: C67.2, C68.2, C69.2, C70.2, C71.2, C72.2, J33.2, J35.2, J37.2, R61.2, R62.2, R66.2, R67.2, R71.2, R72.2, U5.3 (GND), U6.3 (GND), U7.3 (GND); also elsewhere on the board
GPS_SCL: J33.3, J35.3, J37.3, R59.2, R64.2, R69.2, U5.5 (SCL), U6.5 (SCL), U7.5 (SCL); also elsewhere on the board
GPS_SDA: J33.4, J35.4, J37.4, R58.2, R63.2, R68.2, U5.6 (SDA), U6.6 (SDA), U7.6 (SDA); also elsewhere on the board
unnamed: JP9.1 (A), R61.1, U5.8 (A1)
unnamed: JP10.1 (A), R62.1, U5.7 (A0)
unnamed: JP11.1 (A), R66.1, U6.8 (A1)
unnamed: JP12.1 (A), R67.1, U6.7 (A0)
unnamed: JP13.1 (A), R71.1, U7.8 (A1)
unnamed: JP14.1 (A), R72.1, U7.7 (A0)

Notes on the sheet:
https://learn.adafruit.com/adafruit-ina219-current-sensor-breakout/downloads

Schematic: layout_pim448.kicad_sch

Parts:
C63: 100nF; C_0805_2012Metric_Pad1.18x1.45mm_HandSolder
C64: 10µF; C_0805_2012Metric_Pad1.18x1.45mm_HandSolder
J29: Motion; PinHeader_1x05_P2.54mm_Vertical

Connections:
+3V3: C63.1, C64.1, J29.5; also elsewhere on the board
/I2C/Motion/INT: J29.2
GND: C63.2, C64.2, J29.1; also elsewhere on the board
GPS_SCL: J29.3; also elsewhere on the board
GPS_SDA: J29.4; also elsewhere on the board

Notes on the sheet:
https://mm.digikey.com/Volume0/opasdata/d220001/medias/docus/306/PIM448_Web.pdf

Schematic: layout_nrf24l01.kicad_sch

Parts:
C73: 100nF; C_0805_2012Metric_Pad1.18x1.45mm_HandSolder
C74: 10µF; C_0805_2012Metric_Pad1.18x1.45mm_HandSolder
C75: 47µF; CP_Radial_D8.0mm_P3.50mm
J38: nRF24L01; PinHeader_2x04_P2.54mm_Vertical

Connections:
+3V3: C73.1, C74.1, C75.1, J38.2; also elsewhere on the board
/SPI/IO_Protection/IN_1: J38.5; also elsewhere on the board
/SPI/IO_Protection/IN_2: J38.4; also elsewhere on the board
/SPI/IO_Protection/IN_3: J38.6; also elsewhere on the board
/SPI/IO_Protection/IN_4: J38.7; also elsewhere on the board
/SPI/IO_Protection/IN_5: J38.3; also elsewhere on the board
/SPI/Long_Range_Communication/IRQ: J38.8
GND: C73.2, C74.2, C75.2, J38.1; also elsewhere on the board

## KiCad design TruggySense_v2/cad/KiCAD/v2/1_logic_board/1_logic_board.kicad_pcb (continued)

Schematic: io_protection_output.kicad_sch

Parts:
D14: LED; LED_PLCC-2_3.4x3.0mm_AK
F11: SMD0805B010TF; Fuse_0805_2012Metric_Pad1.15x1.40mm_HandSolder
JP25: PWM_FUSE; SolderJumper-2_P1.3mm_Open_RoundedPad1.0x1.5mm
R93: 470; R_0805_2012Metric_Pad1.20x1.40mm_HandSolder
R94: 330; R_0805_2012Metric_Pad1.20x1.40mm_HandSolder
R95: 1k; R_0805_2012Metric_Pad1.20x1.40mm_HandSolder
U13: VOS618A; SSOP-4_4.4x2.6mm_P1.27mm

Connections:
/PWM/IO_Protection/GND_OUT_1: R94.2, R95.2; also elsewhere on the board
/PWM/IO_Protection/OUT_1: D14.2 (A), R95.1, U13.3; also elsewhere on the board
/PWM/IO_Protection/VCC_OUT_1: F11.2, JP25.2 (B); also elsewhere on the board
GND: U13.2; also elsewhere on the board
unnamed: D14.1 (K), R94.1
unnamed: F11.1, JP25.1 (A), U13.4
unnamed: R93.2, U13.1
PWM_SERVO: R93.1; also elsewhere on the board

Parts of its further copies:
D15, D16, D17, D18: LED; LED_PLCC-2_3.4x3.0mm_AK
F12, F13, F14, F15: SMD0805B010TF; Fuse_0805_2012Metric_Pad1.15x1.40mm_HandSolder
JP26, JP27, JP28, JP29: PWM_FUSE; SolderJumper-2_P1.3mm_Open_RoundedPad1.0x1.5mm
R96, R99, R102, R105: 470; R_0805_2012Metric_Pad1.20x1.40mm_HandSolder
R97, R100, R103, R106: 330; R_0805_2012Metric_Pad1.20x1.40mm_HandSolder
R98, R101, R104, R107: 1k; R_0805_2012Metric_Pad1.20x1.40mm_HandSolder
U14, U15, U16, U17: VOS618A; SSOP-4_4.4x2.6mm_P1.27mm

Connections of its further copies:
/PWM/IO_Protection/GND_OUT_2: R97.2, R98.2; also elsewhere on the board
/PWM/IO_Protection/GND_OUT_3: R100.2, R101.2; also elsewhere on the board
/PWM/IO_Protection/GND_OUT_4: R103.2, R104.2; also elsewhere on the board
/PWM/IO_Protection/GND_OUT_5: R106.2, R107.2; also elsewhere on the board
/PWM/IO_Protection/OUT_2: D15.2 (A), R98.1, U14.3; also elsewhere on the board
/PWM/IO_Protection/OUT_3: D16.2 (A), R101.1, U15.3; also elsewhere on the board
/PWM/IO_Protection/OUT_4: D17.2 (A), R104.1, U16.3; also elsewhere on the board
/PWM/IO_Protection/OUT_5: D18.2 (A), R107.1, U17.3; also elsewhere on the board
/PWM/IO_Protection/VCC_OUT_2: F12.2, JP26.2 (B); also elsewhere on the board
/PWM/IO_Protection/VCC_OUT_3: F13.2, JP27.2 (B); also elsewhere on the board
/PWM/IO_Protection/VCC_OUT_4: F14.2, JP28.2 (B); also elsewhere on the board
/PWM/IO_Protection/VCC_OUT_5: F15.2, JP29.2 (B); also elsewhere on the board
GND: U14.2, U15.2, U16.2, U17.2; also elsewhere on the board
unnamed: D15.1 (K), R97.1
unnamed: D16.1 (K), R100.1
unnamed: D17.1 (K), R103.1
unnamed: D18.1 (K), R106.1
unnamed: F12.1, JP26.1 (A), U14.4
unnamed: F13.1, JP27.1 (A), U15.4
unnamed: F14.1, JP28.1 (A), U16.4
unnamed: F15.1, JP29.1 (A), U17.4
unnamed: R96.2, U14.1
unnamed: R99.2, U15.1
unnamed: R102.2, U16.1
unnamed: R105.2, U17.1
PWM_M_FL: R99.1; also elsewhere on the board
PWM_M_FR: R96.1; also elsewhere on the board
PWM_M_RL: R105.1; also elsewhere on the board
PWM_M_RR: R102.1; also elsewhere on the board

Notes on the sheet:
V_{f} = 1.3V (LED forward voltage) I_{f(max)} = 50mA R1 = (V_{IN} - V_{f})/I_{f} = (3.3V -1.3V)/5mA = 400Ω --> 470Ω
I_{max} = 100mA @ 5V
I_{max} = 4.26mA @ 3.3V

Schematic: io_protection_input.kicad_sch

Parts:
D4: TVS_SMF3.3; Nexperia_DSN1608-2_1.6x0.8mm
F1: SMD0805B010TF; Fuse_0805_2012Metric_Pad1.15x1.40mm_HandSolder

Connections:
/ADC/IO_Protection/ADC Buffer 1/IN_1: D4.1 (K), F1.2; also elsewhere on the board
/ADC/IO_Protection/IN_1: F1.1; also elsewhere on the board
GND: D4.2 (A); also elsewhere on the board

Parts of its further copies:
D5, D6, D7, D8, D9, D10, D11, D12, D13, D19, D20, D21, D22, D23, D24, D25, D26, D27, D28, D29, D30, D31, D32, D33, D34, D35: TVS_SMF3.3; Nexperia_DSN1608-2_1.6x0.8mm
F2, F3, F4, F5, F6, F7, F8, F9, F10, F16, F17, F18, F19, F20, F21, F22, F23, F24, F25, F26, F27, F28, F29, F30, F31, F32: SMD0805B010TF; Fuse_0805_2012Metric_Pad1.15x1.40mm_HandSolder
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

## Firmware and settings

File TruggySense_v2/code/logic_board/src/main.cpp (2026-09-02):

/**
 * @file main.cpp
 * @author Robbe Elsermans (creator)
 * @author Thomas Kramp (revisor)
 * @brief Main sketch of the project.
 * @version 2.0
 * @date 2026-05-25
 * 
 * @copyright Copyright (c) 2025 Robbe Elsermans, All rights reserved.
 * This project is released under the CC BY-NC-SA licence.
 * See licence.txt for more information.
 */
#include "tasks.h"

uint8_t adcResolution = 10;
uint8_t sampleSize = 12;

Print &debugSerial = Serial;
HardwareSerial &ibusSerial = Serial8;
HardwareSerial &gpsSerial = Serial5;

I2C &i2c;

uint8_t tasks_initialized = 0;

LED *indicator_led;

Motor *steering_servo;
Motor *motor_fr;
Motor *motor_fl;
Motor *motor_rr;
Motor *motor_rl;
Fan   *cooling_fan;

FS_X6B *remote_control_receiver;
radio_t radio_data;

U_BLOX *gnss_gps;
localization_t gps_data;

Encoder *encoder_fr;
Encoder *encoder_fl;
Encoder *encoder_rr;
Encoder *encoder_rl;
encoder_t encoder_data;

Supply *voltage_sensor_bc_1;
Supply *voltage_sensor_bc_2;
Supply *voltage_sensor_bc_3;
Supply *voltage_sensor_bc_4;
Supply *voltage_sensor_3V3;
Supply *voltage_sensor_5V0;
voltage_t voltage_data;

ACS758 *high_current_sensor_fr;
ACS758 *high_current_sensor_fl;
ACS758 *high_current_sensor_rr;
ACS758 *high_current_sensor_rl;
INA219 *low_current_sensor_hlc;
INA219 *low_current_sensor_llc;
INA219 *low_current_sensor_etc;
current_t current_data;

LM75 *temperature_sensor_llc;
LM75 *temperature_sensor_hlc;
LM75 *temperature_sensor_bp;
LM75 *temperature_sensor_ss;
LM75 *temperature_sensor_bm_1;
LM75 *temperature_sensor_bm_2;
LM75 *temperature_sensor_bm_3;
LM75 *temperature_sensor_bm_4;
LM75 *temperature_sensor_esc_1;
LM75 *temperature_sensor_esc_2;
LM75 *temperature_sensor_esc_3;
LM75 *temperature_sensor_esc_4;
temperature_t temperature_data;

// PIM448 *imu_sensor;
BNO085 *imu_sensor;
movement_t movement_data;

SDCard *sd_logger;
nRF24 *wireless_logger;
logging_data_t log_data;

//#define SHOW_STARTUP

void setup() {
    Serial.begin(115200);

    #ifdef SHOW_STARTUP
        //while (!Serial) {}
        debugSerial.println("Start initialisation");
    #endif
    
    // Initialize system
    if (!initializeTasks()) {
      debugSerial.println("An error occured during startup!");
      indicator_led->write(LOW);
    }
}

// main.tex line 1900

void loop() { }

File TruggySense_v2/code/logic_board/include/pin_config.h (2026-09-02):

/**
 * @file pin_config.h
 * @author Thomas Kramp (creator)
 * @brief Pin configurations for the TruggySense project.
 * @version 1.0
 * @date 2026-05-25
 * 
 * @copyright Copyright (c) 2026 Thomas Kramp, All rights reserved.
 * This project is released under the CC BY-NC-SA licence.
 * See licence.txt for more information.
 */
#ifndef PIN_CONFIG_H_
#define PIN_CONFIG_H_

#pragma once

#define PIN_LED             32  /** @brief Pin definition of the indicator led. */

#define PIN_SERVO            2  /** @brief Pin definition of the steering servo. */

#define PIN_FR_MOTOR         3  /** @brief Pin definition of EXC of the front right Wheel motor. */
#define PIN_FL_MOTOR         4  /** @brief Pin definition of EXC of the front left Wheel motor. */
#define PIN_RR_MOTOR         5  /** @brief Pin definition of EXC of the rear right Wheel motor. */
#define PIN_RL_MOTOR         6  /** @brief Pin definition of EXC of the rear left Wheel motor. */

#define PIN_FAN             33  /** @brief Pin definition of the cooling fan. */

#define PIN_FR_ENCODER      24  /** @brief Pin definition of the front right wheel encoder. */
#define PIN_FL_ENCODER      25  /** @brief Pin definition of the front left wheel encoder. */
#define PIN_RR_ENCODER      26  /** @brief Pin definition of the rear right wheel encoder. */
#define PIN_RL_ENCODER      27  /** @brief Pin definition of the rear left wheel encoder. */

#define PIN_BATTERY_CELL_1  14  /** @brief Pin definition of the battery cell ranging from:  3.2V -  4.2V*/
#define PIN_BATTERY_CELL_2  15  /** @brief Pin definition of the battery cell ranging from:  6.4V -  8.4V*/
#define PIN_BATTERY_CELL_3  16  /** @brief Pin definition of the battery cell ranging from:  9.6V - 12.6V*/
#define PIN_BATTERY_CELL_4  17  /** @brief Pin definition of the battery cell ranging from: 12.8V - 16.8V*/
#define PIN_3V3_RAIL        40  /** @brief Pin definition of the voltage rail ranging from:  3.3V -  3.3V*/
#define PIN_5V0_RAIL        41  /** @brief Pin definition of the voltage rail ranging from:  4.8V -  5.1V*/

#define PIN_FR_HIGH_CURRENT 22  /** @brief Pin definition of the front right wheel's high current sensor. */
#define PIN_FL_HIGH_CURRENT 23  /** @brief Pin definition of the front left wheel's high current sensor. */
#define PIN_RR_HIGH_CURRENT 38  /** @brief Pin definition of the rear right wheel's high current sensor. */
#define PIN_RL_HIGH_CURRENT 39  /** @brief Pin definition of the rear left wheel's high current sensor. */

#define PIN_LONG_RANGE_CE    9  /** @brief Pin definition of the chip enable of the wireless data logger. */
#define PIN_LONG_RANGE_CSN  10  /** @brief Pin definition of the chip select of the wireless data logger. */

#endif
